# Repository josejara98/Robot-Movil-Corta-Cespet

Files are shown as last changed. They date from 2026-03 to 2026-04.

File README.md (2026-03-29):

# 🤖 Prototipo de Robot móvil Cortacésped

Este repositorio contiene el diseño de hardware y el firmware base para la unidad de control central de un robot móvil cortacésped teleoperado

El núcleo de este proyecto es una **PCB personalizada**  diseñada para gestionar potencia, navegación y sistema de seguridad utilizando el microcontrolador **ESP32-S3**.

## Especificaciones Técnicas de la PCB

Nuestra especialización se centra en la integración de sensores y la gestión de actuadores de potencia:

### Cerebro y Conectividad
* **MCU:** `ESP32-S3-WROOM-1`. Doble núcleo con soporte nativo para Wi-Fi y Bluetooth

### Sistema de Seguridad y Detección de Obstáculos
El robot implementa una estrategia de seguridad de dos niveles:
1.  **Nivel Preventivo (Ultrasonidos):** 3 sensores ultrasónicos estratégicamente posicionados para la detección de obstáculos a distancia
2.  **Nivel de Contacto (Bumpers):** 4 finales de carrera instalados en el chasis como "Bumpers". Funcionan como la última barrera física
* **Regulación:** `LDL1117S33R`. LDO de alta eficiencia para una alimentación estable de 3.3V.
* **Precisión de Batería:** `ADS1015LIDGSR`. ADC externo de 12 bits para un monitoreo crítico del voltaje

### Navegación y Movimiento
* **IMU:** `IIM-42652`. Sensor de 6 ejes de grado industrial para mantener el rumbo y detectar inclinaciones peligrosas.
* **Control de Tracción:** Pines de salida (Dupont) para conectar un **driver de motor DC externo** para el desplazamiento del robot.

### Sistema de Corte (Brushless)
La PCB cuenta con salidas específicas para controlar **3 ESC (Electronic Speed Controllers)** independientes:
* **2 Motores Brushless:** Dedicados al corte principal de césped.
* **1 Motor Brushless:** Dedicado a la función de bordeadora

### Interfaz de Usuario
* **Buzzer SMT:** `CMI-9705-0580-SMT-TR`. Notifica mediante códigos acústicos:
    * **Movimiento inminente:** Alerta antes de activar cuchillas o tracción.
    * **Batería Baja:** Alerta de retorno a base.

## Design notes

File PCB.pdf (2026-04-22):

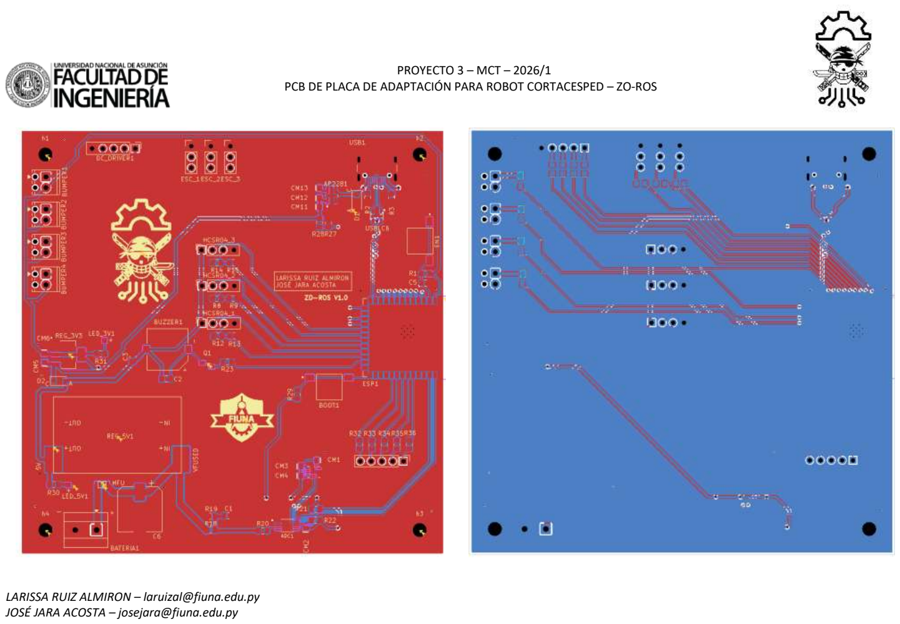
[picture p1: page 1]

PROYECTO 3 – MCT – 2026/1
PCB DE PLACA DE ADAPTACIÓN PARA ROBOT CORTACESPED – ZO-ROS

LARISSA RUIZ ALMIRON – laruizal@fiuna.edu.py JOSÉ JARA ACOSTA – josejara@fiuna.edu.py

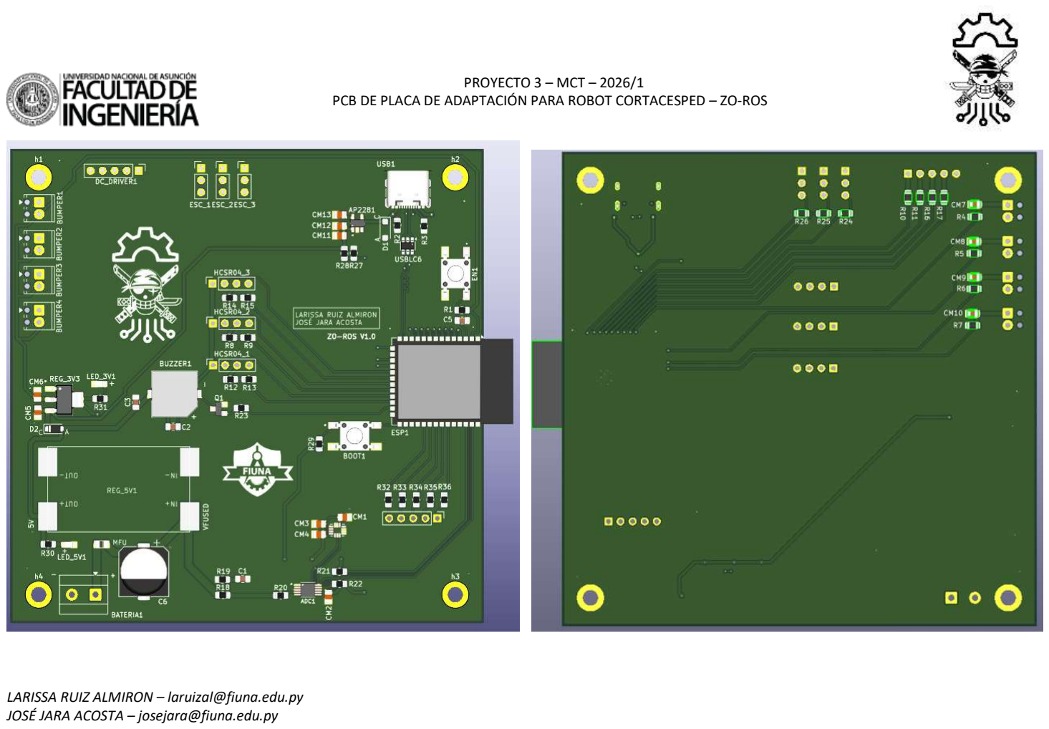
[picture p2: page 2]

PROYECTO 3 – MCT – 2026/1
PCB DE PLACA DE ADAPTACIÓN PARA ROBOT CORTACESPED – ZO-ROS

LARISSA RUIZ ALMIRON – laruizal@fiuna.edu.py JOSÉ JARA ACOSTA – josejara@fiuna.edu.py

PROYECTO 3 – MCT – 2026/1
PCB DE PLACA DE ADAPTACIÓN PARA ROBOT CORTACESPED – ZO-ROS

LARISSA RUIZ ALMIRON – laruizal@fiuna.edu.py JOSÉ JARA ACOSTA – josejara@fiuna.edu.py

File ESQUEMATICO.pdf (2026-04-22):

PROYECTO 3 – MCT – 2026/1
ESQUEMATICO DE PLACA DE ADAPTACIÓN PARA ROBOT CORTACESPED – ZO-ROS

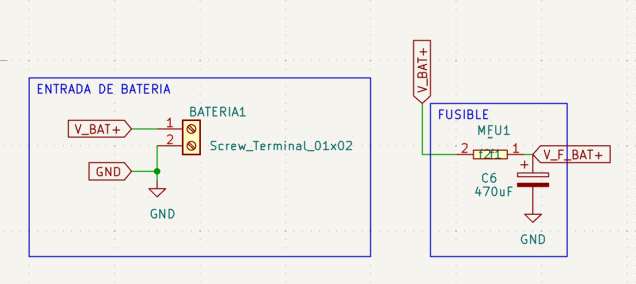
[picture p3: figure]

LARISSA RUIZ ALMIRON – laruizal@fiuna.edu.py JOSÉ JARA ACOSTA – josejara@fiuna.edu.py

En el diseño de la placa se planteó una arquitectura modular, separando claramente las funciones principales del sistema para facilitar

tanto el análisis como la implementación física

La alimentación del sistema comienza en la entrada de

batería, donde se utiliza una bornera para asegurar una

conexión firme. Inmediatamente después se incorpora un

fusible, con el objetivo de proteger la placa frente a

sobrecorrientes o posibles cortocircuitos. Además, se

añadió un capacitor electrolítico de 470 µF, cuya función es

estabilizar la tensión de entrada y absorber variaciones

bruscas provocadas principalmente por el funcionamiento

de los motores.

PROYECTO 3 – MCT – 2026/1
ESQUEMATICO DE PLACA DE ADAPTACIÓN PARA ROBOT CORTACESPED – ZO-ROS

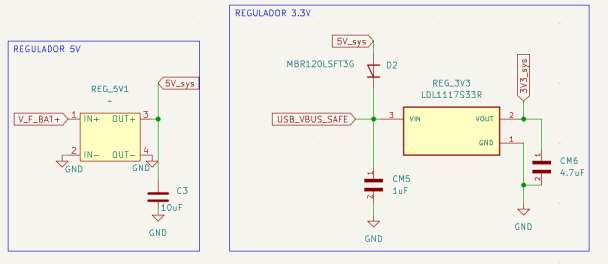
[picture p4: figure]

LARISSA RUIZ ALMIRON – laruizal@fiuna.edu.py JOSÉ JARA ACOSTA – josejara@fiuna.edu.py

A partir de la alimentación, se implementa un regulador tipo buck para obtener una línea de 5V. Esta elección se debe a que el sistema trabaja con una batería cuyo voltaje es superior, y un regulador lineal no sería eficiente debido a las pérdidas térmicas. El capacitor en la salida del regulador ayuda a mantener una tensión más estable frente a cambios de carga.

Posteriormente, se genera la línea de 3.3V mediante un regulador LDO, ya que este nivel es requerido por el ESP32 y varios sensores. Se incluyó un diodo Schottky en la entrada del regulador para evitar corrientes inversas, especialmente considerando que el sistema también puede alimentarse desde el puerto USB. Los capacitores asociados al regulador cumplen la función de desacople y estabilidad, tal como recomiendan los datasheets.

PROYECTO 3 – MCT – 2026/1
ESQUEMATICO DE PLACA DE ADAPTACIÓN PARA ROBOT CORTACESPED – ZO-ROS

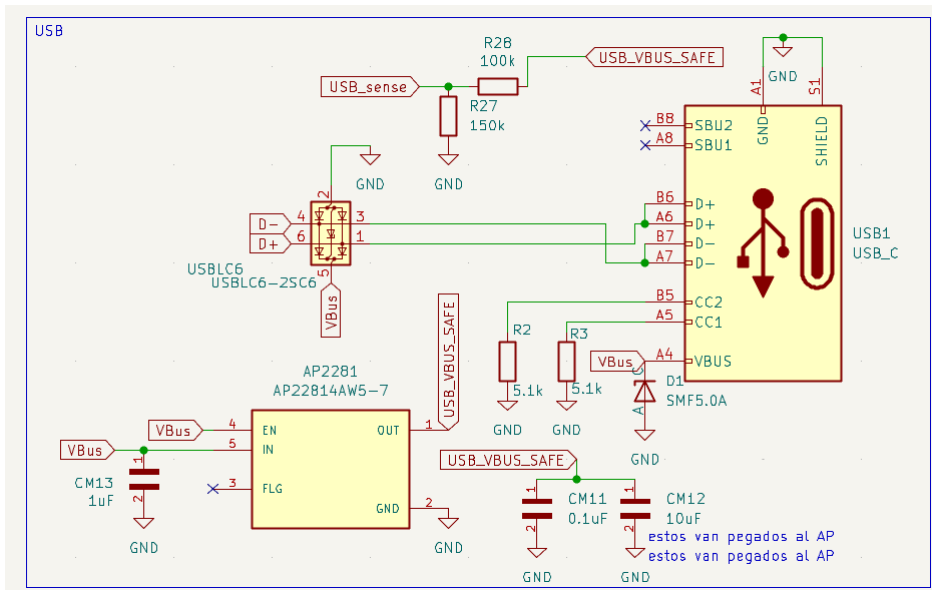
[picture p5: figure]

LARISSA RUIZ ALMIRON – laruizal@fiuna.edu.py JOSÉ JARA ACOSTA – josejara@fiuna.edu.py

El bloque USB fue diseñado no solo para

comunicación, | sino | también | considerando

aspectos de protección. Se incorporó un arreglo de

protección ESD en las líneas de datos y un diodo

TVS en la línea de VBUS para proteger frente a

descargas. Además, se utilizaron resistencias en

las líneas CC para cumplir con la especificación de

USB-C. También se implementa un circuito de

control de alimentación mediante un switch

dedicado, lo que permite gestionar de forma segura

la energía proveniente del USB.

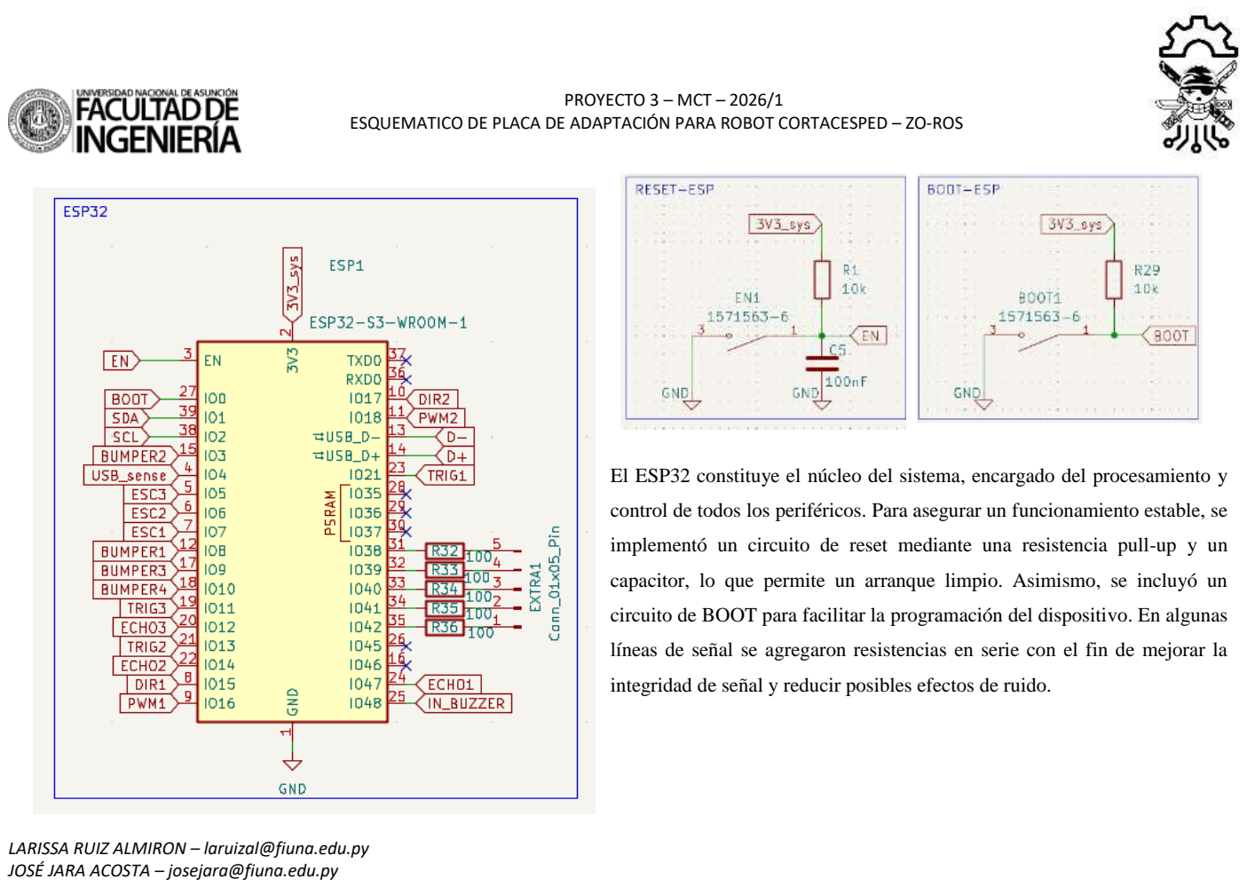
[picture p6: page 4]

PROYECTO 3 – MCT – 2026/1
ESQUEMATICO DE PLACA DE ADAPTACIÓN PARA ROBOT CORTACESPED – ZO-ROS

LARISSA RUIZ ALMIRON – laruizal@fiuna.edu.py JOSÉ JARA ACOSTA – josejara@fiuna.edu.py

El ESP32 constituye el núcleo del sistema, encargado del procesamiento y

control de todos los periféricos. Para asegurar un funcionamiento estable, se

implementó un circuito de reset mediante una resistencia pull-up y un

capacitor, lo que permite un arranque limpio. Asimismo, se incluyó un

circuito de BOOT para facilitar la programación del dispositivo. En algunas

líneas de señal se agregaron resistencias en serie con el fin de mejorar la

integridad de señal y reducir posibles efectos de ruido.

PROYECTO 3 – MCT – 2026/1
ESQUEMATICO DE PLACA DE ADAPTACIÓN PARA ROBOT CORTACESPED – ZO-ROS

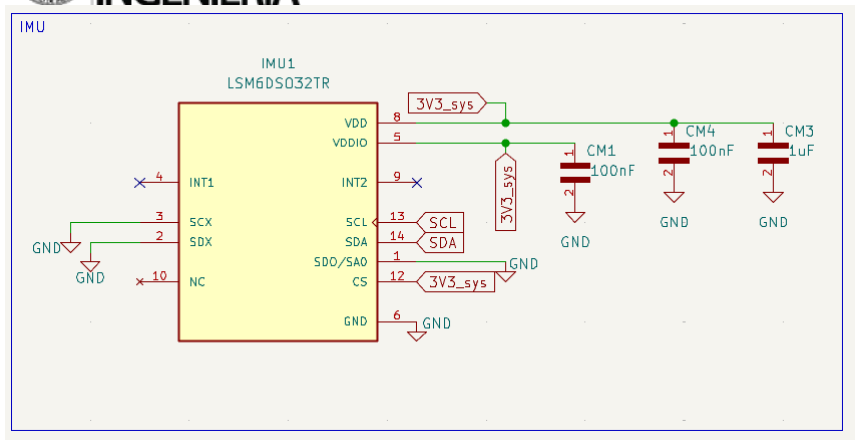
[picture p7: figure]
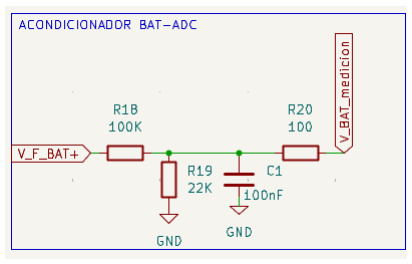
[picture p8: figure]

LARISSA RUIZ ALMIRON – laruizal@fiuna.edu.py JOSÉ JARA ACOSTA – josejara@fiuna.edu.py

En cuanto a los sensores, se incorporó una IMU conectada

mediante I2C, la cual cuenta con capacitores de desacople

ubicados próximos a sus pines de alimentación, siguiendo las

recomendaciones del fabricante. Para la medición de la batería, se

utilizó un ADC externo, ya que el ADC interno del ESP32 no

ofrece la precisión requerida. Este ADC también se comunica

mediante I2C y cuenta con resistencias pull-up adecuadas.

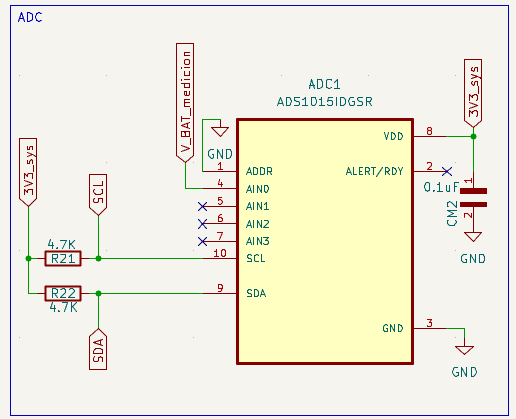
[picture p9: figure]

La medición del voltaje de batería se realiza a través

de un divisor resistivo, el cual reduce la tensión a

un nivel seguro para el ADC. Adicionalmente, se

incorporó un filtro RC para disminuir el ruido

presente en la señal, mejorando así la calidad de la

medición.

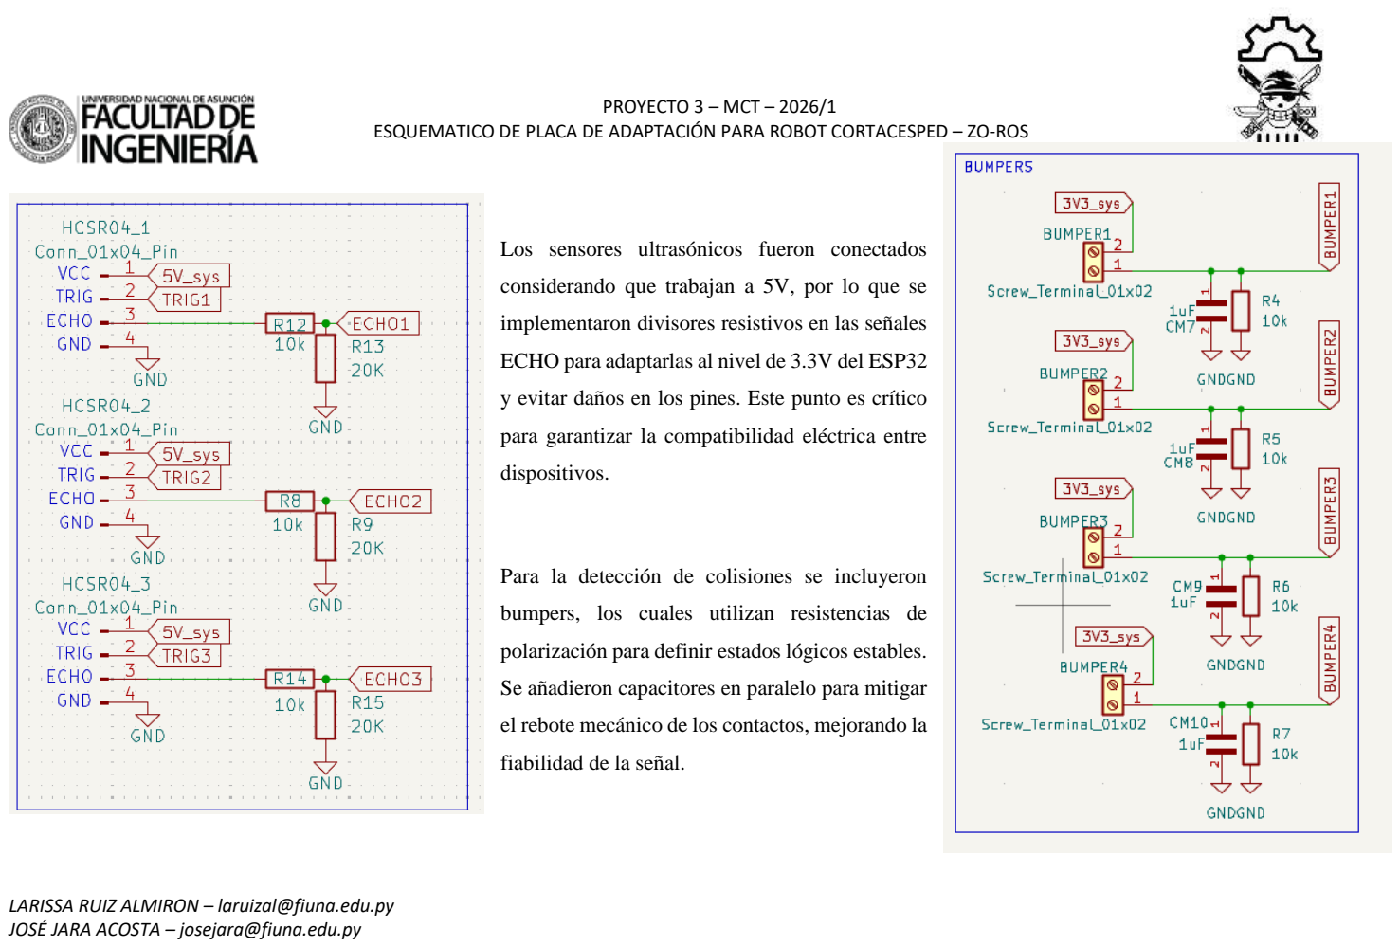
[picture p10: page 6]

PROYECTO 3 – MCT – 2026/1
ESQUEMATICO DE PLACA DE ADAPTACIÓN PARA ROBOT CORTACESPED – ZO-ROS

LARISSA RUIZ ALMIRON – laruizal@fiuna.edu.py JOSÉ JARA ACOSTA – josejara@fiuna.edu.py

Los sensores ultrasónicos fueron conectados

considerando que trabajan a 5V, por lo que se

implementaron divisores resistivos en las señales

ECHO para adaptarlas al nivel de 3.3V del ESP32

y evitar daños en los pines. Este punto es crítico

para garantizar la compatibilidad eléctrica entre

dispositivos.

Para la detección de colisiones se incluyeron

bumpers, los cuales utilizan resistencias de

polarización para definir estados lógicos estables.

Se añadieron capacitores en paralelo para mitigar

el rebote mecánico de los contactos, mejorando la

fiabilidad de la señal.

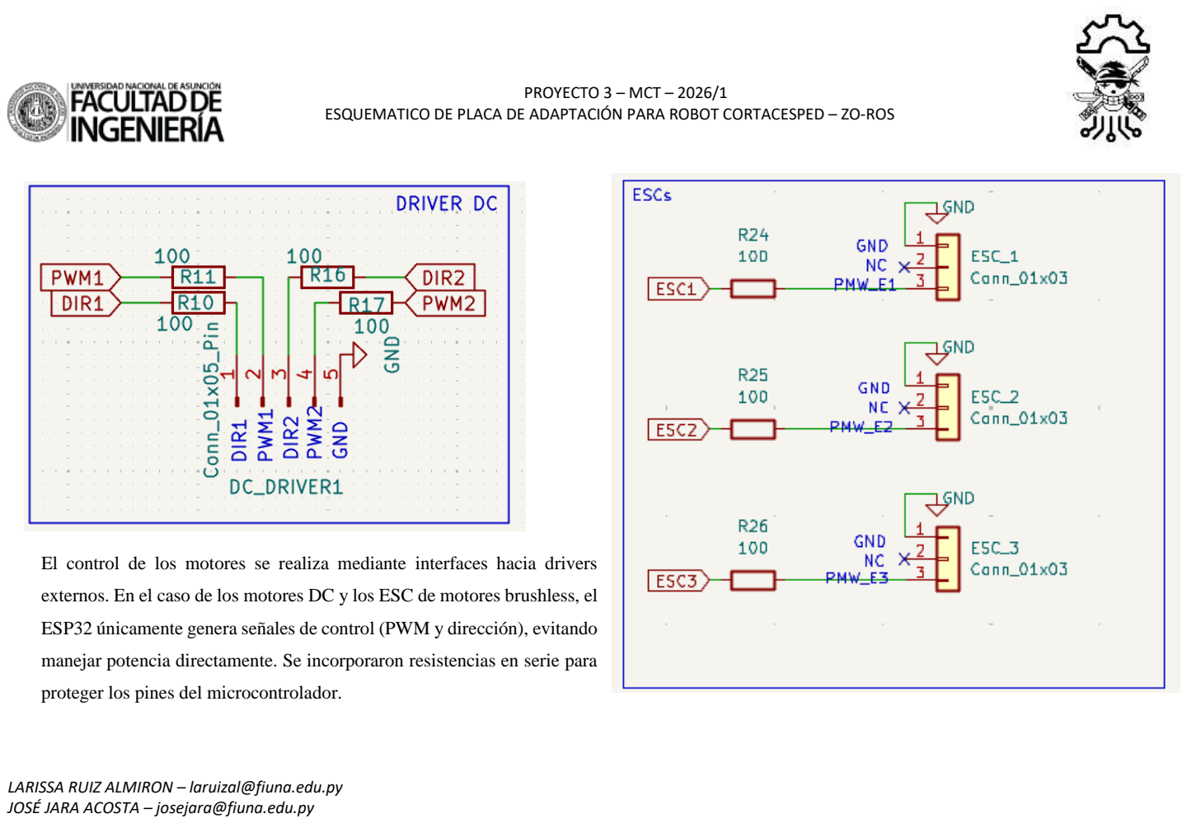
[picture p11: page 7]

PROYECTO 3 – MCT – 2026/1
ESQUEMATICO DE PLACA DE ADAPTACIÓN PARA ROBOT CORTACESPED – ZO-ROS

LARISSA RUIZ ALMIRON – laruizal@fiuna.edu.py JOSÉ JARA ACOSTA – josejara@fiuna.edu.py

El control de los motores se realiza mediante interfaces hacia drivers

externos. En el caso de los motores DC y los ESC de motores brushless, el

ESP32 únicamente genera señales de control (PWM y dirección), evitando

manejar potencia directamente. Se incorporaron resistencias en serie para

proteger los pines del microcontrolador.

PROYECTO 3 – MCT – 2026/1
ESQUEMATICO DE PLACA DE ADAPTACIÓN PARA ROBOT CORTACESPED – ZO-ROS

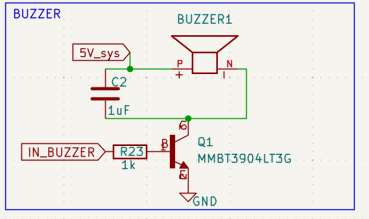
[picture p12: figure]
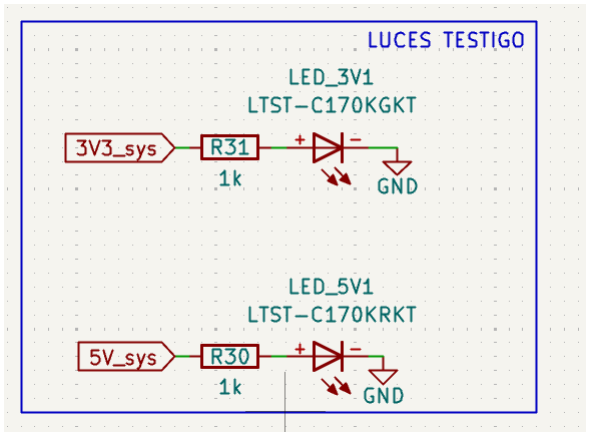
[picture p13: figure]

LARISSA RUIZ ALMIRON – laruizal@fiuna.edu.py JOSÉ JARA ACOSTA – josejara@fiuna.edu.py

El buzzer se controla mediante un transistor en configuración de conmutación, ya que el

ESP32 no puede suministrar la corriente necesaria de forma directa. La resistencia en la

base asegura el correcto funcionamiento del transistor.

Finalmente, se añadieron LEDs indicadores para las líneas de 3.3V y 5V,

lo que permite verificar visualmente el estado de la alimentación del

sistema.

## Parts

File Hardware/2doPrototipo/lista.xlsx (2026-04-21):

Reference | Qty | Value | DNP | Exclude from BOM | Exclude from Board | Footprint | Datasheet
R1,R4,R5,R6,R7,R8,R12,R14,R29 | 9 | 10k |  |  |  | Resistor_SMD:R_0805_2012Metric_Pad1.20x1.40mm_HandSolder | ~
R2,R3 | 2 | 5.1k |  |  |  | Resistor_SMD:R_0805_2012Metric_Pad1.20x1.40mm_HandSolder | ~
R9,R13,R15 | 3 | 20K |  |  |  | Resistor_SMD:R_0805_2012Metric_Pad1.20x1.40mm_HandSolder | ~
R10,R11,R16,R17,R20,R24,R25,R26,R32,R33,R34,R35,R36 | 13 | 100 |  |  |  | Resistor_SMD:R_0805_2012Metric_Pad1.20x1.40mm_HandSolder | ~
R18 | 1 | 100K |  |  |  | Resistor_SMD:R_0805_2012Metric_Pad1.20x1.40mm_HandSolder | ~
R19 | 1 | 22K |  |  |  | Resistor_SMD:R_0805_2012Metric_Pad1.20x1.40mm_HandSolder | ~
R21,R22 | 2 | 4.7K |  |  |  | Resistor_SMD:R_0805_2012Metric_Pad1.20x1.40mm_HandSolder | ~
R23,R30,R31 | 3 | 1k |  |  |  | Resistor_SMD:R_0805_2012Metric_Pad1.20x1.40mm_HandSolder | ~
R27 | 1 | 150k |  |  |  | Resistor_SMD:R_0805_2012Metric_Pad1.20x1.40mm_HandSolder | ~
R28 | 1 | 100k |  |  |  | Resistor_SMD:R_0805_2012Metric_Pad1.20x1.40mm_HandSolder | ~
REG_3V3 | 1 | LDL1117S33R |  |  |  | LDL1117S33R:SOT230P700X180-4N
REG_5V1 | 1 | ~ |  |  |  | Mini590.pretty:MINI590
USB1 | 1 | USB_C |  |  |  | Connector_USB:USB_C_Receptacle_GCT_USB4105-xx-A_16P_TopMnt_Horizontal | https://www.usb.org/sites/default/files/documents/usb_type-c.zip
USBLC6 | 1 | USBLC6-2SC6 |  |  |  | Package_TO_SOT_SMD:SOT-23-6 | https://www.st.com/resource/en/datasheet/usblc6-2.pdf

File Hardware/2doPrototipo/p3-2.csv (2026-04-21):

Reference | Qty | Value | DNP | Exclude from BOM | Exclude from Board | Footprint | Datasheet
ADC1 | 1 | ADS1015IDGSR |  |  |  | ADS1015IDGSR:SOP50P490X110-10N
AP2281 | 1 | AP22814AW5-7 |  |  |  | AP22814AW5-7:SOT95P285X140-5N
BATERIA1 | 1 | Screw_Terminal_01x02 |  |  |  | TerminalBlock_MetzConnect:TerminalBlock_MetzConnect_Type055_RT01502HDWU_1x02_P5.00mm_Horizontal | ~
BOOT1,EN1 | 2 | 1571563-6 |  |  |  | 1571563-6:SW_1571563-6
BUMPER1,BUMPER2,BUMPER3,BUMPER4 | 4 | Screw_Terminal_01x02 |  |  |  | TerminalBlock_Phoenix:TerminalBlock_Phoenix_MPT-0,5-2-2.54_1x02_P2.54mm_Horizontal | ~
BUZZER1 | 1 | CMI-9705-0580-SMT-TR |  |  |  | CMI-9705-0580-SMT-TR:CUI_CMI-9705-0580-SMT-TR
C1,C5 | 2 | 100nF |  |  |  | Capacitor_SMD:C_0805_2012Metric_Pad1.18x1.45mm_HandSolder | ~
C2 | 1 | 1uF |  |  |  | Capacitor_SMD:C_0805_2012Metric_Pad1.18x1.45mm_HandSolder | ~
C3 | 1 | 10uF |  |  |  | Capacitor_SMD:C_0805_2012Metric_Pad1.18x1.45mm_HandSolder | ~
C6 | 1 | 470uF |  |  |  | Capacitor_SMD:CP_Elec_10x10 | ~
CM1,CM4 | 2 | 100nF |  |  |  | 08056D104KAT2A:CAPC2012X140N
CM2,CM11 | 2 | 0.1uF |  |  |  | 08056D104KAT2A:CAPC2012X140N
CM3,CM5,CM7,CM8,CM9,CM10,CM13 | 7 | 1uF |  |  |  | 08056D104KAT2A:CAPC2012X140N
CM6 | 1 | 4.7uF |  |  |  | 08056D104KAT2A:CAPC2012X140N
CM12 | 1 | 10uF |  |  |  | 08056D104KAT2A:CAPC2012X140N
D1 | 1 | SMF5.0A |  |  |  | SMF5.0A:P37_SOD-123FL | https://diotec.com/de/produktliste/Z.html
D2 | 1 | MBR120LSFT3G |  |  |  | SMF5.0A:P37_SOD-123FL | https://diotec.com/de/produktliste/Z.html
DC_DRIVER1,EXTRA1 | 2 | Conn_01x05_Pin |  |  |  | Connector_PinHeader_2.54mm:PinHeader_1x05_P2.54mm_Vertical | ~
ESC_1,ESC_2,ESC_3 | 3 | Conn_01x03 |  |  |  | Connector_PinHeader_2.54mm:PinHeader_1x03_P2.54mm_Vertical | ~
ESP1 | 1 | ESP32-S3-WROOM-1 |  |  |  | RF_Module:ESP32-S3-WROOM-1 | https://www.espressif.com/sites/default/files/documentation/esp32-s3-wroom-1_wroom-1u_datasheet_en.pdf
HCSR04_1,HCSR04_2,HCSR04_3 | 3 | Conn_01x04_Pin |  |  |  | Connector_PinSocket_2.54mm:PinSocket_1x04_P2.54mm_Vertical | ~
IMU1 | 1 | LSM6DSO32TR |  |  |  | LSM6DSO32TR:XDCR_LSM6DSO32TR
LED_3V1 | 1 | LTST-C170KGKT |  |  |  | LTST-C170KGKT:DIOC200X125X110
LED_5V1 | 1 | LTST-C170KRKT |  |  |  | LTST-C170KRKT:DIOC200X125X110
MFU1 | 1 | ~ |  |  |  | MFU0805FF01000PW00.pretty:MFU0805FF01000PW00
Q1 | 1 | MMBT3904LT3G |  |  |  | MMBT3904LT3G:SOT23
R1,R4,R5,R6,R7,R8,R12,R14,R29 | 9 | 10k |  |  |  | Resistor_SMD:R_0805_2012Metric_Pad1.20x1.40mm_HandSolder | ~
R2,R3 | 2 | 5.1k |  |  |  | Resistor_SMD:R_0805_2012Metric_Pad1.20x1.40mm_HandSolder | ~
R9,R13,R15 | 3 | 20K |  |  |  | Resistor_SMD:R_0805_2012Metric_Pad1.20x1.40mm_HandSolder | ~
R10,R11,R16,R17,R20,R24,R25,R26,R32,R33,R34,R35,R36 | 13 | 100 |  |  |  | Resistor_SMD:R_0805_2012Metric_Pad1.20x1.40mm_HandSolder | ~
R18 | 1 | 100K |  |  |  | Resistor_SMD:R_0805_2012Metric_Pad1.20x1.40mm_HandSolder | ~
R19 | 1 | 22K |  |  |  | Resistor_SMD:R_0805_2012Metric_Pad1.20x1.40mm_HandSolder | ~
R21,R22 | 2 | 4.7K |  |  |  | Resistor_SMD:R_0805_2012Metric_Pad1.20x1.40mm_HandSolder | ~
R23,R30,R31 | 3 | 1k |  |  |  | Resistor_SMD:R_0805_2012Metric_Pad1.20x1.40mm_HandSolder | ~
R27 | 1 | 150k |  |  |  | Resistor_SMD:R_0805_2012Metric_Pad1.20x1.40mm_HandSolder | ~
R28 | 1 | 100k |  |  |  | Resistor_SMD:R_0805_2012Metric_Pad1.20x1.40mm_HandSolder | ~
REG_3V3 | 1 | LDL1117S33R |  |  |  | LDL1117S33R:SOT230P700X180-4N
REG_5V1 | 1 | ~ |  |  |  | Mini590.pretty:MINI590
USB1 | 1 | USB_C |  |  |  | Connector_USB:USB_C_Receptacle_GCT_USB4105-xx-A_16P_TopMnt_Horizontal | https://www.usb.org/sites/default/files/documents/usb_type-c.zip
USBLC6 | 1 | USBLC6-2SC6 |  |  |  | Package_TO_SOT_SMD:SOT-23-6 | https://www.st.com/resource/en/datasheet/usblc6-2.pdf

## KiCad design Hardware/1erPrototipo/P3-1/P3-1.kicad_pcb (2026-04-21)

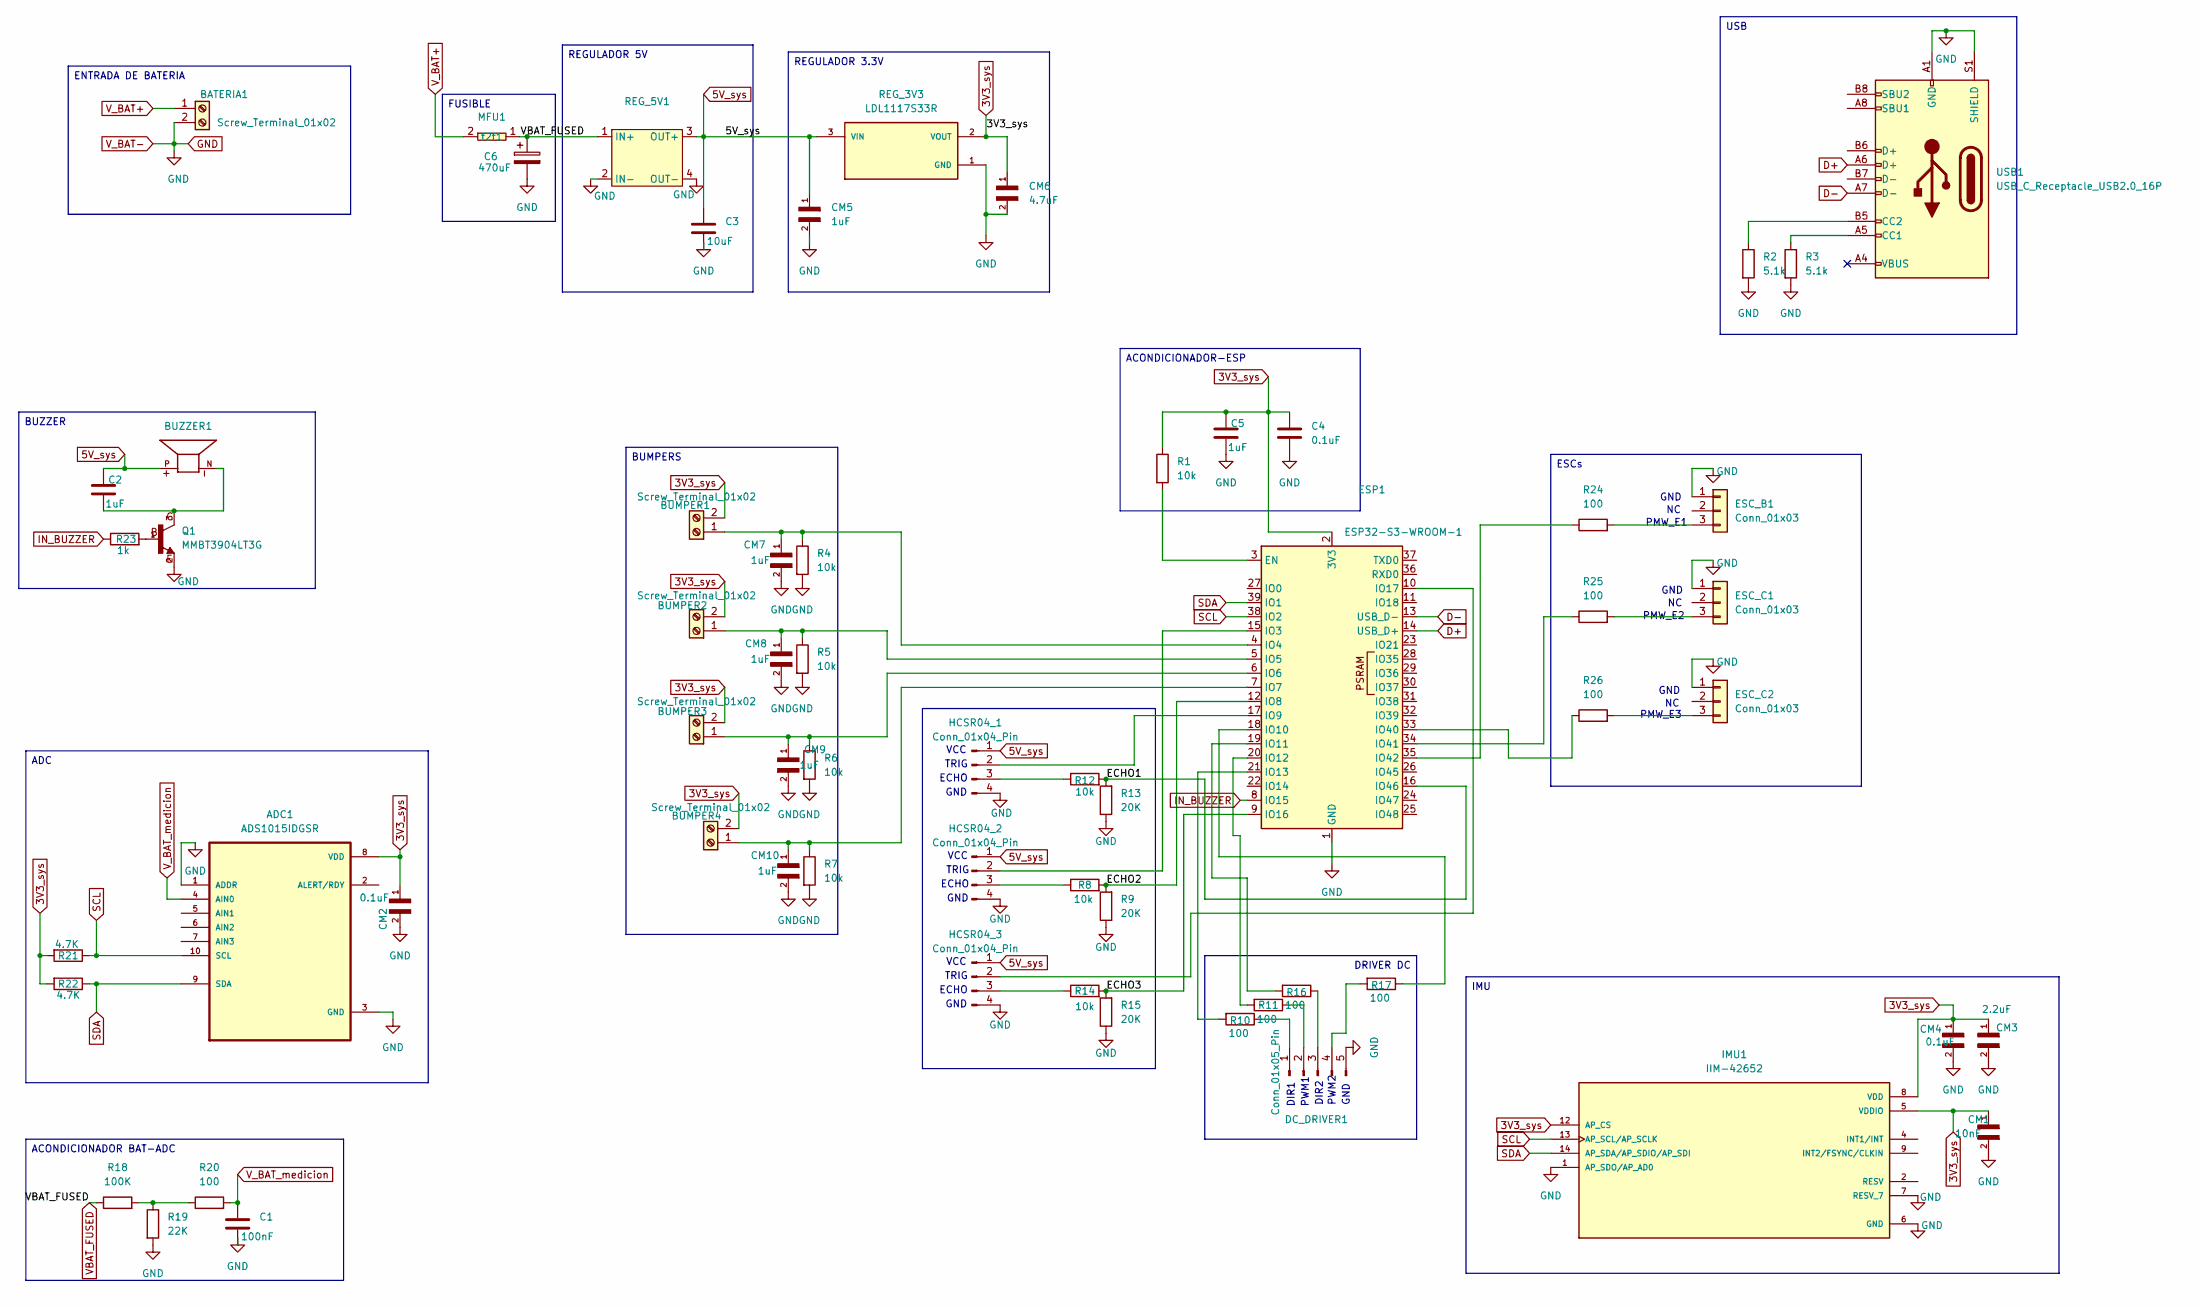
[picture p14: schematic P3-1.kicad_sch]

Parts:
ADC1: ADS1015IDGSR; SOP50P490X110-10N
BATERIA1: Screw_Terminal_01x02; TerminalBlock_MetzConnect_Type055_RT01502HDWU_1x02_P5.00mm_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
BUMPER1, BUMPER2, BUMPER3, BUMPER4: Screw_Terminal_01x02; TerminalBlock_Phoenix_MPT-0,5-2-2.54_1x02_P2.54mm_Horizontal
BUZZER1: CMI-9705-0580-SMT-TR; CUI_CMI-9705-0580-SMT-TR; PARTREV 1.0
C1: 100nF; C_0805_2012Metric_Pad1.18x1.45mm_HandSolder
C2, C5: 1uF; C_0805_2012Metric_Pad1.18x1.45mm_HandSolder
C3: 10uF; C_0805_2012Metric_Pad1.18x1.45mm_HandSolder
C4: 0.1uF; C_0805_2012Metric_Pad1.18x1.45mm_HandSolder
C6: 470uF; CP_Elec_10x10
CM1: 10nF; CAPC2012X140N; DigiKey_Part_Number 478-08056D104KAT2ACT-ND
CM2, CM4: 0.1uF; CAPC2012X140N; DigiKey_Part_Number 478-08056D104KAT2ACT-ND
CM3: 2.2uF; CAPC2012X140N; DigiKey_Part_Number 478-08056D104KAT2ACT-ND
CM5, CM7, CM8, CM9, CM10: 1uF; CAPC2012X140N; DigiKey_Part_Number 478-08056D104KAT2ACT-ND
CM6: 4.7uF; CAPC2012X140N; DigiKey_Part_Number 478-08056D104KAT2ACT-ND
DC_DRIVER1: Conn_01x05_Pin; PinHeader_1x05_P2.54mm_Vertical
ESC_B1: Conn_01x03; PinHeader_1x03_P2.54mm_Vertical
ESC_C1, ESC_C2: Conn_01x03; PinHeader_1x03_P2.54mm_Vertical
ESP1: ESP32-S3-WROOM-1
HCSR04_1, HCSR04_2, HCSR04_3: Conn_01x04_Pin; PinSocket_1x04_P2.54mm_Vertical
IMU1: IIM-42652; PQFN50P250X300X97-14N; PARTREV 1.0
MFU1: MFU0603FF01000PW00
Q1: MMBT3904LT3G; SOT23; DigiKey_Part_Number MMBT3904LT3GOSCT-ND
R1, R4, R5, R6, R7, R8, R12, R14: 10k; R_0805_2012Metric_Pad1.20x1.40mm_HandSolder
R2, R3: 5.1k; R_0805_2012Metric_Pad1.20x1.40mm_HandSolder
R9, R13, R15: 20K; R_0805_2012Metric_Pad1.20x1.40mm_HandSolder
R10, R11, R16, R17, R20, R24, R25, R26: 100; R_0805_2012Metric_Pad1.20x1.40mm_HandSolder
R18: 100K; R_0805_2012Metric_Pad1.20x1.40mm_HandSolder
R19: 22K; R_0805_2012Metric_Pad1.20x1.40mm_HandSolder
R21, R22: 4.7K; R_0805_2012Metric_Pad1.20x1.40mm_HandSolder
R23: 1k; R_0805_2012Metric_Pad1.20x1.40mm_HandSolder
REG_3V3: LDL1117S33R; SOT230P700X180-4N; PARTREV 7
REG_5V1: MINI590
USB1: USB_C_Receptacle_USB2.0_16P; USB_C_Receptacle_GCT_USB4105-xx-A_16P_TopMnt_Horizontal

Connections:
3V3_sys: ADC1.8 (VDD), BUMPER1.2, BUMPER2.2, BUMPER3.2, BUMPER4.2, C4.1, C5.1, CM1.1, CM2.1, CM3.1, CM4.1, CM6.1, ESP1.2 (3V3), IMU1.5 (VDDIO), IMU1.8 (VDD), IMU1.12 (AP_CS), R1.1, R21.2, R22.2, REG_3V3.2 (VOUT), REG_3V3.4 (VOUT)
5V_sys: BUZZER1.P, C2.1, C3.1, CM5.1, HCSR04_1.1, HCSR04_2.1, HCSR04_3.1, REG_3V3.3 (VIN), REG_5V1.3 (OUT+)
/ECHO1: ESP1.16 (IO46), R12.2, R13.2
/ECHO2: ESP1.12 (IO8), R8.2, R9.2
/ECHO3: ESP1.9 (IO16), R14.2, R15.2
D+: ESP1.14 (USB_D+), USB1.A6 (D+)
D-: ESP1.13 (USB_D-), USB1.A7 (D-)
GND: ADC1.1 (ADDR), ADC1.3 (GND), BATERIA1.2, C1.2, C3.2, C4.2, C5.2, C6.2, CM1.2, CM2.2, CM3.2, CM4.2, CM5.2, CM6.2, CM7.2, CM8.2, CM9.2, CM10.2, DC_DRIVER1.5, ESC_B1.1, ESC_C1.1, ESC_C2.1, ESP1.1 (GND), ESP1.40 (GND), ESP1.41 (GND), HCSR04_1.4, HCSR04_2.4, HCSR04_3.4, IMU1.1 (AP_SDO/AP_AD0), IMU1.6 (GND), IMU1.7 (RESV_7), Q1.2, R2.2, R3.2, R4.2, R5.2, R6.2, R7.2, R9.1, R13.1, R15.1, R19.2, REG_3V3.1 (GND), REG_5V1.2 (IN-), REG_5V1.4 (OUT-), USB1.A1 (GND), USB1.A12 (GND), USB1.B1 (GND), USB1.B12 (GND), USB1.S1 (SHIELD)
IN_BUZZER: ESP1.8 (IO15), R23.1
unnamed: BUMPER1.1, CM7.1, ESP1.4 (IO4), R4.1
unnamed: BUMPER2.1, CM8.1, ESP1.5 (IO5), R5.1
unnamed: BUMPER3.1, CM9.1, ESP1.6 (IO6), R6.1
unnamed: BUMPER4.1, CM10.1, ESP1.7 (IO7), R7.1
unnamed: BUZZER1.N, C2.2, Q1.3
unnamed: DC_DRIVER1.1, R10.1
unnamed: DC_DRIVER1.2, R11.1
unnamed: DC_DRIVER1.3, R16.1
unnamed: DC_DRIVER1.4, R17.2
unnamed: ESC_B1.3, R24.2
unnamed: ESC_C1.3, R25.2
unnamed: ESC_C2.3, R26.2
unnamed: ESP1.3 (EN), R1.2
unnamed: ESP1.15 (IO3), HCSR04_2.2
unnamed: ESP1.17 (IO9), HCSR04_1.2
unnamed: ESP1.18 (IO10), R17.1
unnamed: ESP1.19 (IO11), R16.2
unnamed: ESP1.20 (IO12), R11.2
unnamed: ESP1.21 (IO13), R10.2
unnamed: ESP1.10 (IO17), HCSR04_3.2
unnamed: ESP1.33 (IO40), R26.1
unnamed: ESP1.34 (IO41), R25.1
unnamed: ESP1.35 (IO42), R24.1
unnamed: HCSR04_1.3, R12.1
unnamed: HCSR04_2.3, R8.1
unnamed: HCSR04_3.3, R14.1
unnamed: IMU1.2 (RESV), IMU1.3 (RESV), IMU1.10 (RESV), IMU1.11 (RESV)
unnamed: Q1.1, R23.2
unnamed: R18.2, R19.1, R20.1
unnamed: R3.1, USB1.A5 (CC1)
unnamed: R2.1, USB1.B5 (CC2)
SCL: ADC1.10 (SCL), ESP1.38 (IO2), IMU1.13 (AP_SCL/AP_SCLK), R21.1
SDA: ADC1.9 (SDA), ESP1.39 (IO1), IMU1.14 (AP_SDA/AP_SDIO/AP_SDI), R22.1
VBAT_FUSED: C6.1, MFU1.1 (f1), R18.1, REG_5V1.1 (IN+)
V_BAT+: BATERIA1.1, MFU1.2 (f2)
V_BAT_medicion: ADC1.4 (AIN0), C1.1, R20.2

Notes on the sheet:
TRIG
PWM2
GND
VCC
GND
ECHO
PMW_E2
PMW_E3
DIR2
DIR1
PWM1
PMW_E1
ADC
REGULADOR 3.3V
ENTRADA DE BATERIA
DRIVER DC
ACONDICIONADOR-ESP
BUMPERS
BUZZER
REGULADOR 5V
ESCs
ACONDICIONADOR BAT-ADC
USB
IMU
FUSIBLE

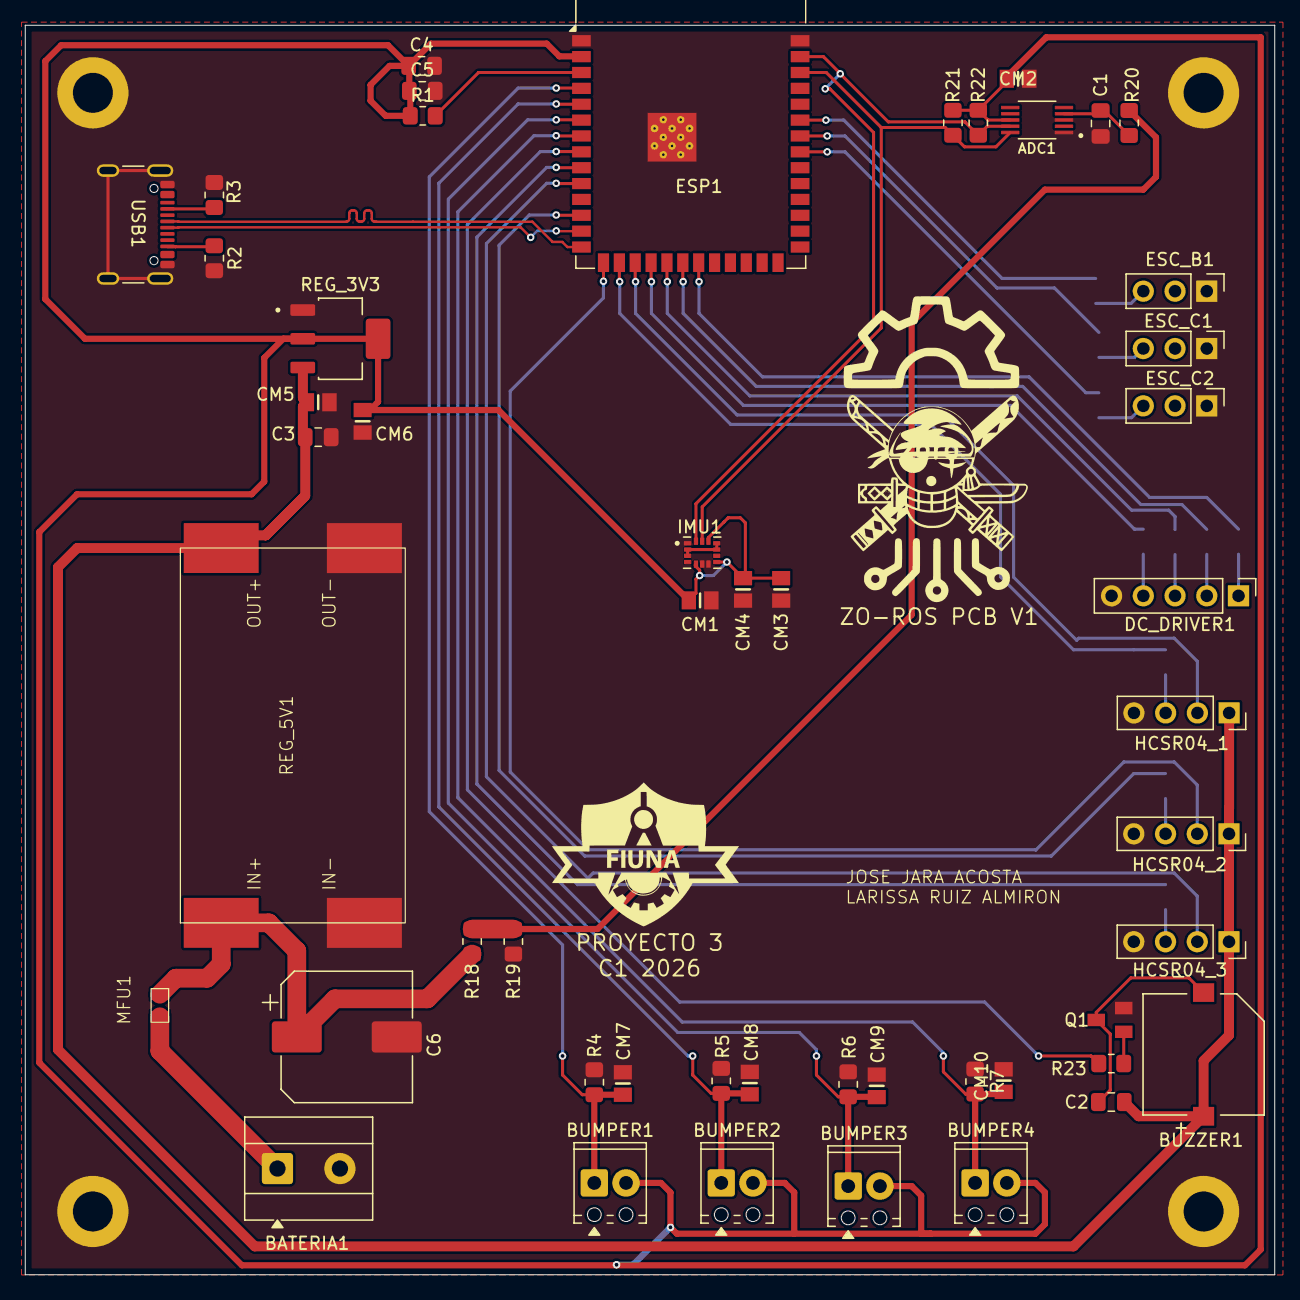
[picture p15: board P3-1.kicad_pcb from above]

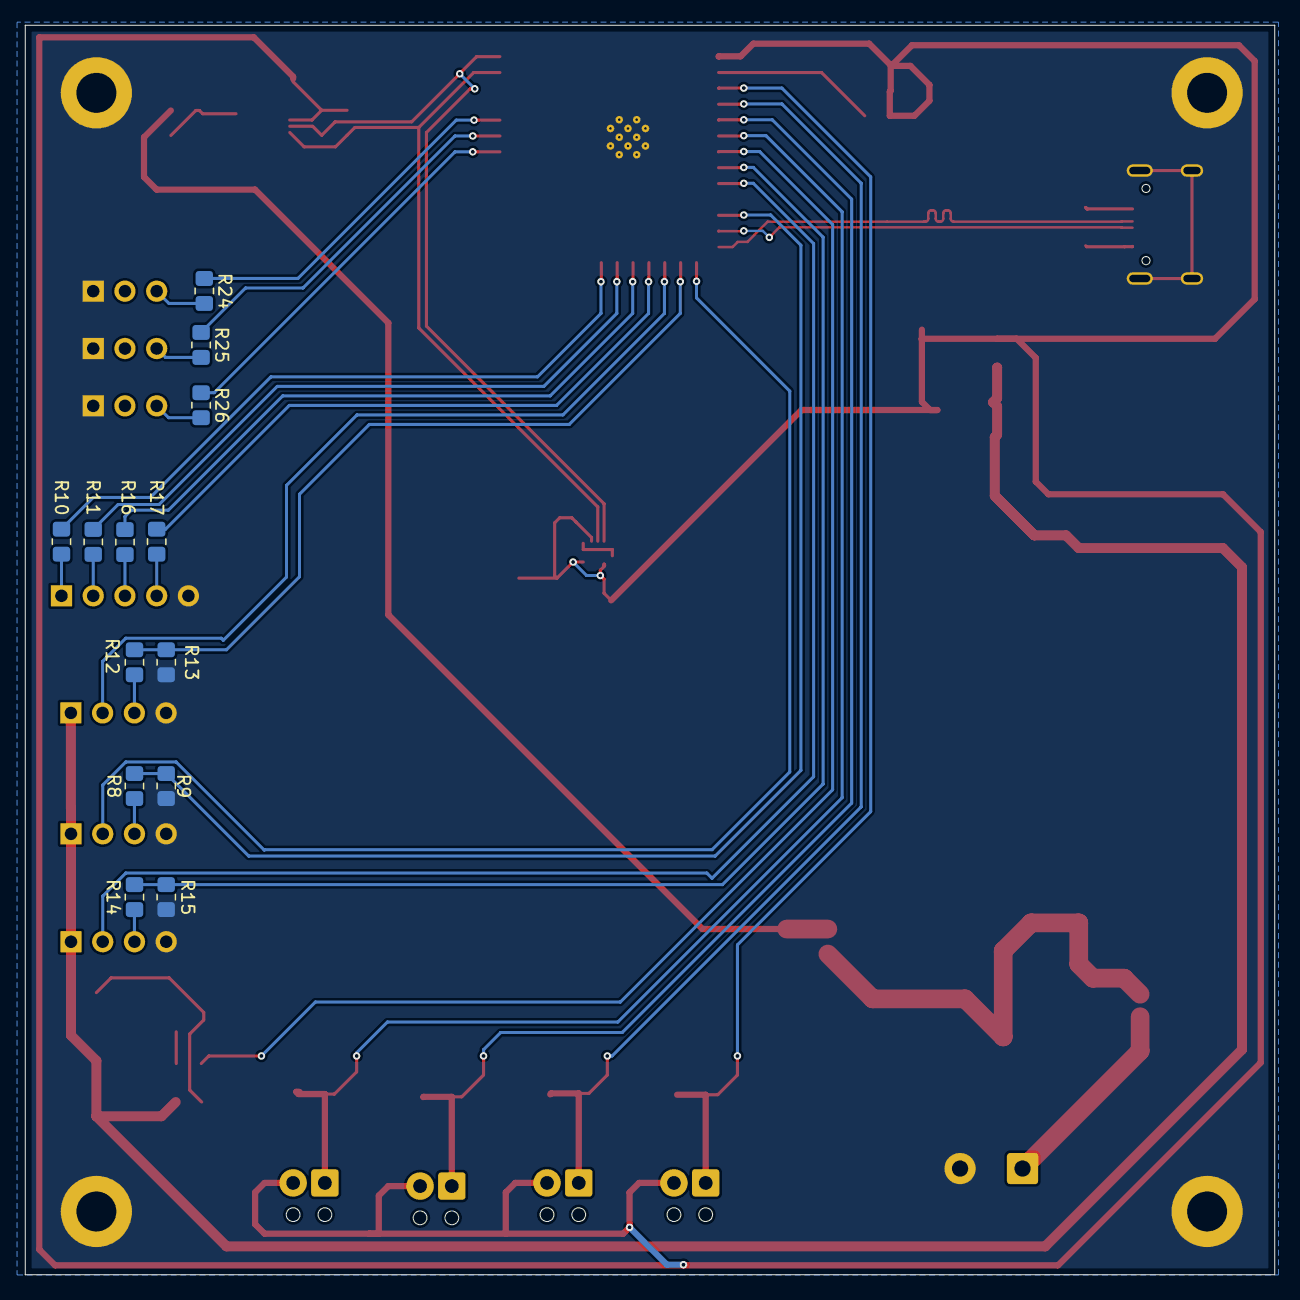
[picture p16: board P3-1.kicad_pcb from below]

Board: 2 copper layers, 100.0 x 100.0 mm, 64 parts (13 on the bottom side), 45 nets.

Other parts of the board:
zoro: LOGO; zoro

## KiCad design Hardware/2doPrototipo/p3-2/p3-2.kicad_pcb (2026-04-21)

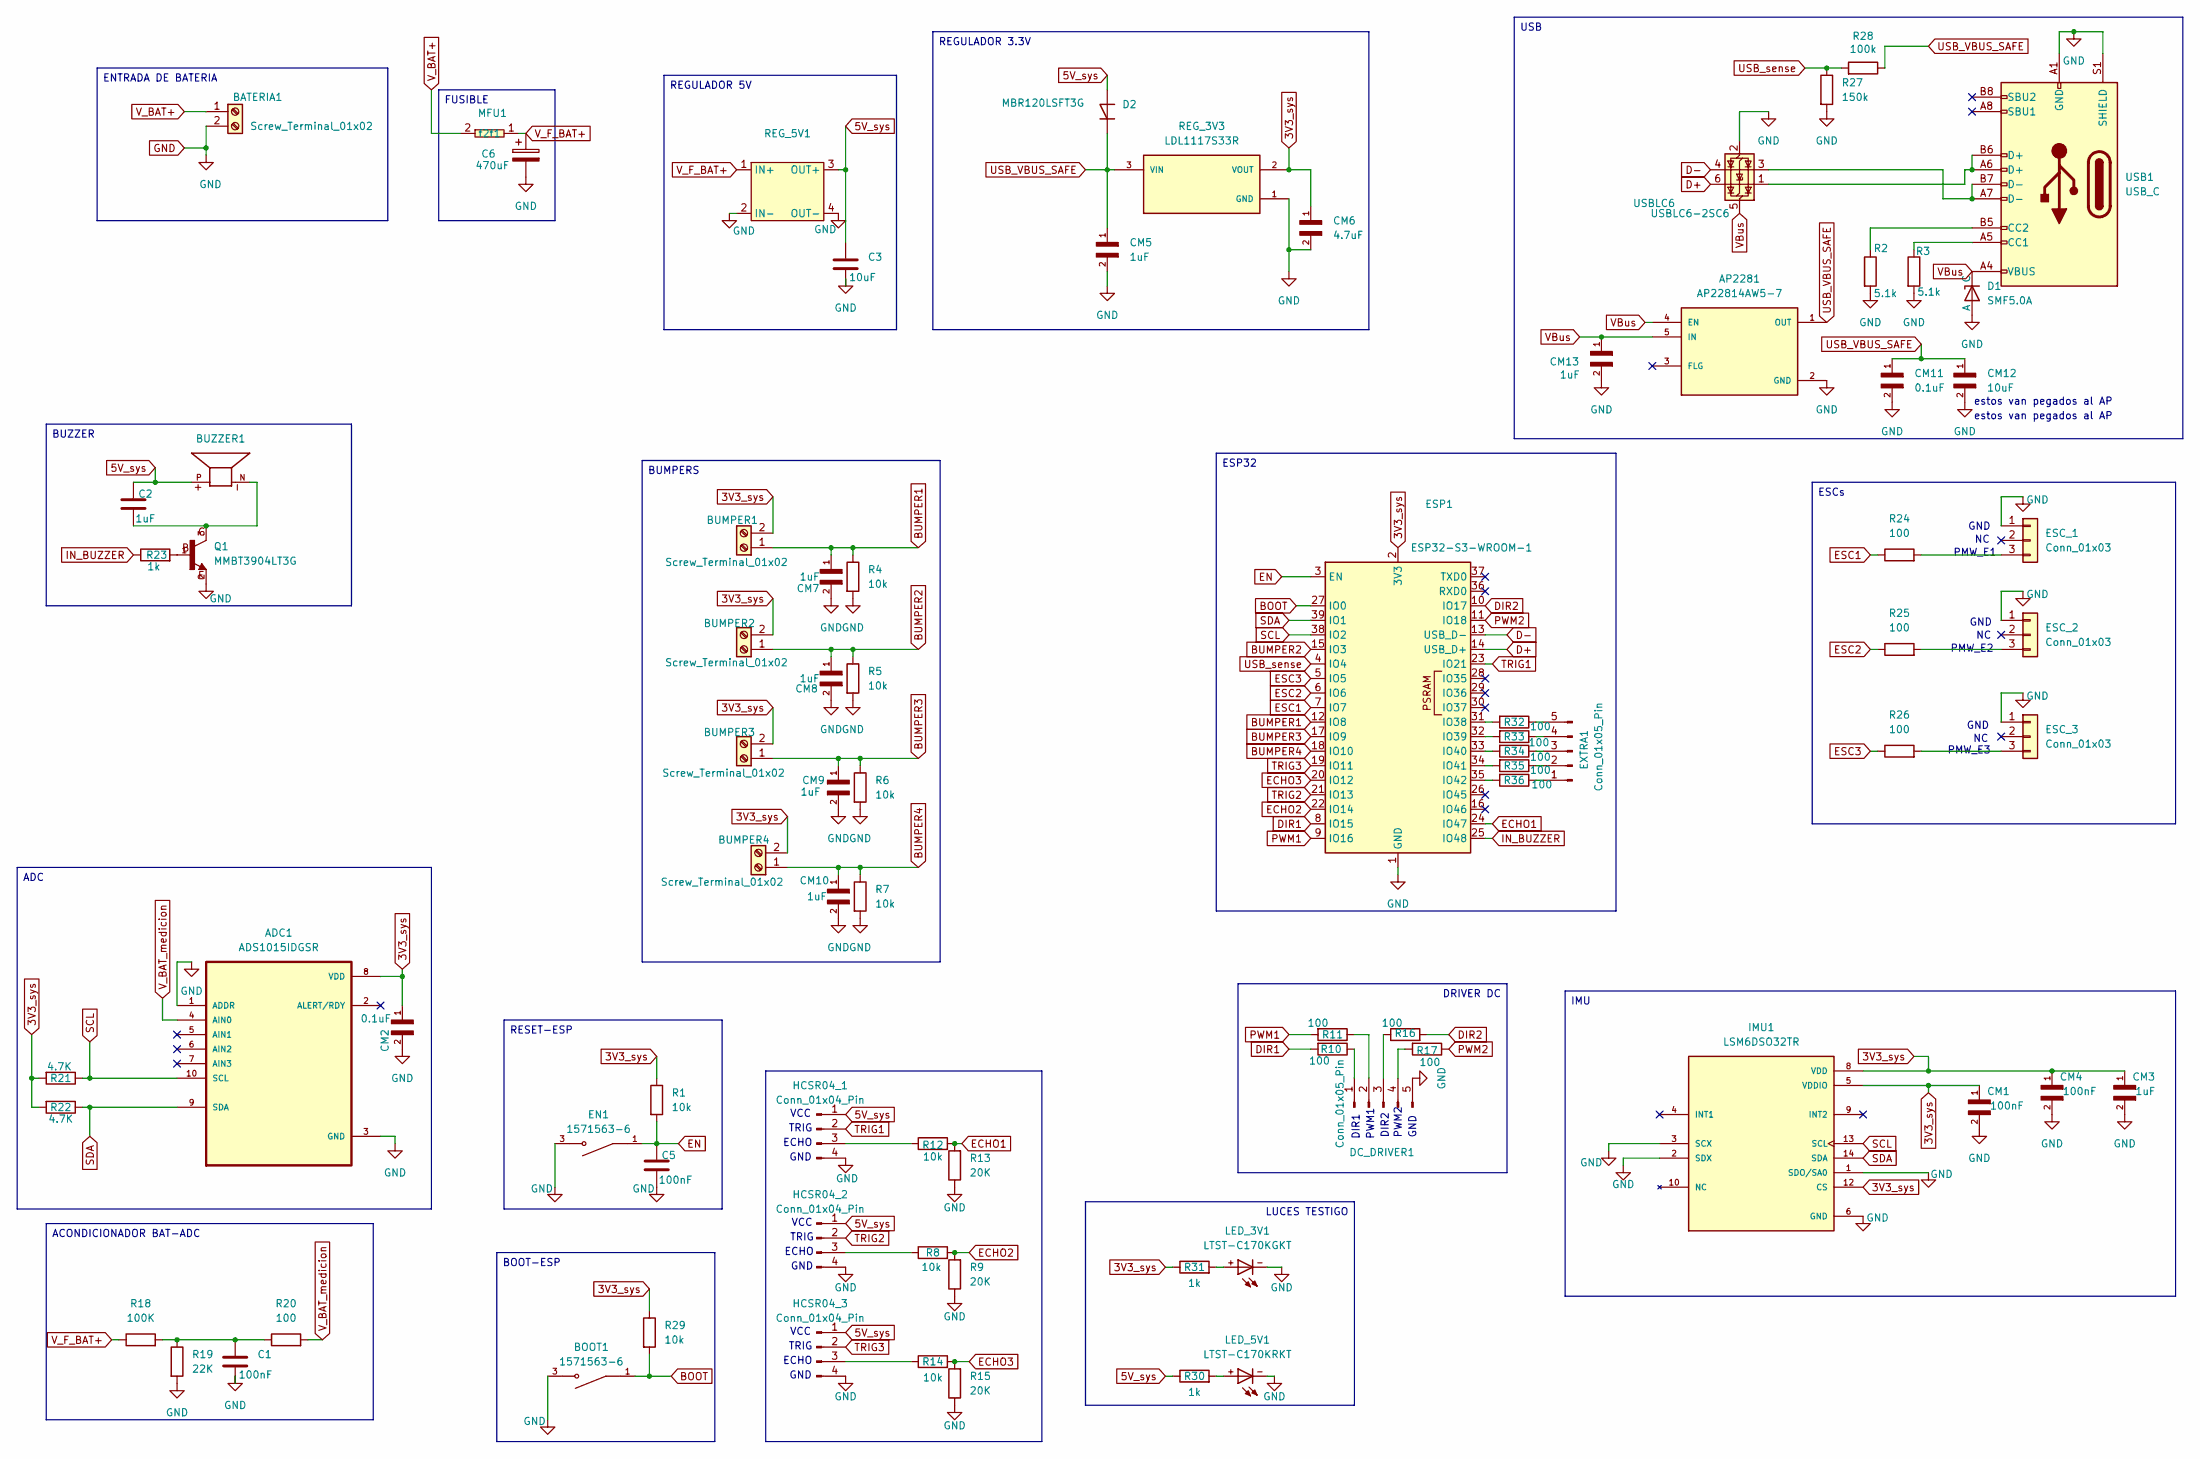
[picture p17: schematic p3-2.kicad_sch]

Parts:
ADC1: ADS1015IDGSR; SOP50P490X110-10N
AP2281: AP22814AW5-7; SOT95P285X140-5N; PARTREV 1
BATERIA1: Screw_Terminal_01x02; TerminalBlock_MetzConnect_Type055_RT01502HDWU_1x02_P5.00mm_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
BOOT1: 1571563-6; SW_1571563-6; PARTREV V
BUMPER1, BUMPER2, BUMPER3, BUMPER4: Screw_Terminal_01x02; TerminalBlock_Phoenix_MPT-0,5-2-2.54_1x02_P2.54mm_Horizontal
BUZZER1: CMI-9705-0580-SMT-TR; CUI_CMI-9705-0580-SMT-TR; PARTREV 1.0
C1, C5: 100nF; C_0805_2012Metric_Pad1.18x1.45mm_HandSolder
C2: 1uF; C_0805_2012Metric_Pad1.18x1.45mm_HandSolder
C3: 10uF; C_0805_2012Metric_Pad1.18x1.45mm_HandSolder
C6: 470uF; CP_Elec_10x10
CM1, CM4: 100nF; CAPC2012X140N; DigiKey_Part_Number 478-08056D104KAT2ACT-ND
CM2, CM11: 0.1uF; CAPC2012X140N; DigiKey_Part_Number 478-08056D104KAT2ACT-ND
CM3, CM5, CM7, CM8, CM9, CM10, CM13: 1uF; CAPC2012X140N; DigiKey_Part_Number 478-08056D104KAT2ACT-ND
CM6: 4.7uF; CAPC2012X140N; DigiKey_Part_Number 478-08056D104KAT2ACT-ND
CM12: 10uF; CAPC2012X140N; DigiKey_Part_Number 478-08056D104KAT2ACT-ND
D1: SMF5.0A; P37_SOD-123FL
D2: MBR120LSFT3G; D_SOD-123F
DC_DRIVER1: Conn_01x05_Pin; PinHeader_1x05_P2.54mm_Vertical
EN1: 1571563-6; SW_1571563-6; PARTREV V
ESC_1, ESC_2, ESC_3: Conn_01x03; PinHeader_1x03_P2.54mm_Vertical
ESP1: ESP32-S3-WROOM-1
EXTRA1: Conn_01x05_Pin; PinHeader_1x05_P2.54mm_Vertical
HCSR04_1, HCSR04_2, HCSR04_3: Conn_01x04_Pin; PinSocket_1x04_P2.54mm_Vertical
IMU1: LSM6DSO32TR; XDCR_LSM6DSO32TR; PARTREV 1
LED_3V1: LTST-C170KGKT; DIOC200X125X110
LED_5V1: LTST-C170KRKT; DIOC200X125X110
MFU1: MFU0805FF01000PW00
Q1: MMBT3904LT3G; SOT23; DigiKey_Part_Number MMBT3904LT3GOSCT-ND
R1, R4, R5, R6, R7, R8, R12, R14, R29: 10k; R_0805_2012Metric_Pad1.20x1.40mm_HandSolder
R2, R3: 5.1k; R_0805_2012Metric_Pad1.20x1.40mm_HandSolder
R9, R13, R15: 20K; R_0805_2012Metric_Pad1.20x1.40mm_HandSolder
R10, R11, R16, R17, R20, R24, R25, R26, R32, R33, R34, R35, R36: 100; R_0805_2012Metric_Pad1.20x1.40mm_HandSolder
R18: 100K; R_0805_2012Metric_Pad1.20x1.40mm_HandSolder
R19: 22K; R_0805_2012Metric_Pad1.20x1.40mm_HandSolder
R21, R22: 4.7K; R_0805_2012Metric_Pad1.20x1.40mm_HandSolder
R23, R30, R31: 1k; R_0805_2012Metric_Pad1.20x1.40mm_HandSolder
R27: 150k; R_0805_2012Metric_Pad1.20x1.40mm_HandSolder
R28: 100k; R_0805_2012Metric_Pad1.20x1.40mm_HandSolder
REG_3V3: LDL1117S33R; SOT230P700X180-4N; PARTREV 7
REG_5V1: MINI590
USB1: USB_C; USB_C_Receptacle_GCT_USB4105-xx-A_16P_TopMnt_Horizontal
USBLC6: USBLC6-2SC6; SOT-23-6

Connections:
3V3_sys: ADC1.8 (VDD), BUMPER1.2, BUMPER2.2, BUMPER3.2, BUMPER4.2, CM1.1, CM2.1, CM3.1, CM4.1, CM6.1, ESP1.2 (3V3), IMU1.5 (VDDIO), IMU1.8 (VDD), IMU1.12 (CS), R1.1, R21.2, R22.2, R29.1, R31.1, REG_3V3.2 (VOUT), REG_3V3.4 (VOUT)
5V_sys: BUZZER1.P, C2.1, C3.1, D2.2 (A), HCSR04_1.1, HCSR04_2.1, HCSR04_3.1, R30.1, REG_5V1.3 (OUT+)
BOOT: BOOT1.1, BOOT1.2, ESP1.27 (IO0), R29.2
BUMPER1: BUMPER1.1, CM7.1, ESP1.12 (IO8), R4.1
BUMPER2: BUMPER2.1, CM8.1, ESP1.15 (IO3), R5.1
BUMPER3: BUMPER3.1, CM9.1, ESP1.17 (IO9), R6.1
BUMPER4: BUMPER4.1, CM10.1, ESP1.18 (IO10), R7.1
D+: ESP1.14 (USB_D+), USBLC6.6 (I/O1)
D-: ESP1.13 (USB_D-), USBLC6.4 (I/O2)
DIR1: ESP1.8 (IO15), R10.2
DIR2: ESP1.10 (IO17), R16.2
ECHO1: ESP1.24 (IO47), R12.2, R13.2
ECHO2: ESP1.22 (IO14), R8.2, R9.2
ECHO3: ESP1.20 (IO12), R14.2, R15.2
EN: C5.1, EN1.1, EN1.2, ESP1.3 (EN), R1.2
ESC1: ESP1.7 (IO7), R24.1
ESC2: ESP1.6 (IO6), R25.1
ESC3: ESP1.5 (IO5), R26.1
GND: ADC1.1 (ADDR), ADC1.3 (GND), AP2281.2 (GND), BATERIA1.2, BOOT1.3, BOOT1.4, C1.2, C3.2, C5.2, C6.2, CM1.2, CM2.2, CM3.2, CM4.2, CM5.2, CM6.2, CM7.2, CM8.2, CM9.2, CM10.2, CM11.2, CM12.2, CM13.2, D1.2 (A), DC_DRIVER1.5, EN1.3, EN1.4, ESC_1.1, ESC_2.1, ESC_3.1, ESP1.1 (GND), ESP1.40 (GND), ESP1.41 (GND), HCSR04_1.4, HCSR04_2.4, HCSR04_3.4, IMU1.1 (SDO/SA0), IMU1.2 (SDX), IMU1.3 (SCX), IMU1.6 (GND), IMU1.7 (GND), LED_3V1.-, LED_5V1.-, Q1.2, R2.2, R3.2, R4.2, R5.2, R6.2, R7.2, R9.1, R13.1, R15.1, R19.2, R27.2, REG_3V3.1 (GND), REG_5V1.2 (IN-), REG_5V1.4 (OUT-), USB1.A1 (GND), USB1.A12 (GND), USB1.B1 (GND), USB1.B12 (GND), USB1.S1 (SHIELD), USBLC6.2 (GND); also elsewhere on the board
IN_BUZZER: ESP1.25 (IO48), R23.1
unnamed: BUZZER1.N, C2.2, Q1.3
unnamed: C1.1, R18.2, R19.1, R20.1
unnamed: DC_DRIVER1.1, R10.1
unnamed: DC_DRIVER1.2, R11.1
unnamed: DC_DRIVER1.3, R16.1
unnamed: DC_DRIVER1.4, R17.2
unnamed: ESC_1.3, R24.2
unnamed: ESC_2.3, R25.2
unnamed: ESC_3.3, R26.2
unnamed: ESP1.31 (IO38), R32.2
unnamed: ESP1.32 (IO39), R33.2
unnamed: ESP1.33 (IO40), R34.2
unnamed: ESP1.34 (IO41), R35.2
unnamed: ESP1.35 (IO42), R36.2
unnamed: EXTRA1.1, R36.1
unnamed: EXTRA1.2, R35.1
unnamed: EXTRA1.3, R34.1
unnamed: EXTRA1.4, R33.1
unnamed: EXTRA1.5, R32.1
unnamed: HCSR04_1.3, R12.1
unnamed: HCSR04_2.3, R8.1
unnamed: HCSR04_3.3, R14.1
unnamed: LED_3V1.+, R31.2
unnamed: LED_5V1.+, R30.2
unnamed: Q1.1, R23.2
unnamed: R3.1, USB1.A5 (CC1)
unnamed: R2.1, USB1.B5 (CC2)
unnamed: USB1.A6 (D+), USB1.B6 (D+), USBLC6.1 (I/O1)
unnamed: USB1.A7 (D-), USB1.B7 (D-), USBLC6.3 (I/O2)
PWM1: ESP1.9 (IO16), R11.2
PWM2: ESP1.11 (IO18), R17.1
SCL: ADC1.10 (SCL), ESP1.38 (IO2), IMU1.13 (SCL), R21.1
SDA: ADC1.9 (SDA), ESP1.39 (IO1), IMU1.14 (SDA), R22.1
TRIG1: ESP1.23 (IO21), HCSR04_1.2
TRIG2: ESP1.21 (IO13), HCSR04_2.2
TRIG3: ESP1.19 (IO11), HCSR04_3.2
USB_VBUS_SAFE: AP2281.1 (OUT), CM5.1, CM11.1, CM12.1, D2.1 (K), R28.1, REG_3V3.3 (VIN)
USB_sense: ESP1.4 (IO4), R27.1, R28.2
VBus: AP2281.4 (EN), AP2281.5 (IN), CM13.1, D1.1 (C), USB1.A4 (VBUS), USB1.A9 (VBUS), USB1.B4 (VBUS), USB1.B9 (VBUS), USBLC6.5 (VBUS)
V_BAT+: BATERIA1.1, MFU1.2 (f2)
V_BAT_medicion: ADC1.4 (AIN0), R20.2
V_F_BAT+: C6.1, MFU1.1 (f1), R18.1, REG_5V1.1 (IN+)

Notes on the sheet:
TRIG
PWM2
GND
estos van pegados al AP
VCC
GND
ECHO
PMW_E2
PMW_E3
DIR2
DIR1
PWM1
PMW_E1
ADC
REGULADOR 3.3V
RESET-ESP
ENTRADA DE BATERIA
DRIVER DC
BUMPERS
BUZZER
BOOT-ESP
ESP32
LUCES TESTIGO
ESCs
ACONDICIONADOR BAT-ADC
USB
REGULADOR 5V
IMU
FUSIBLE

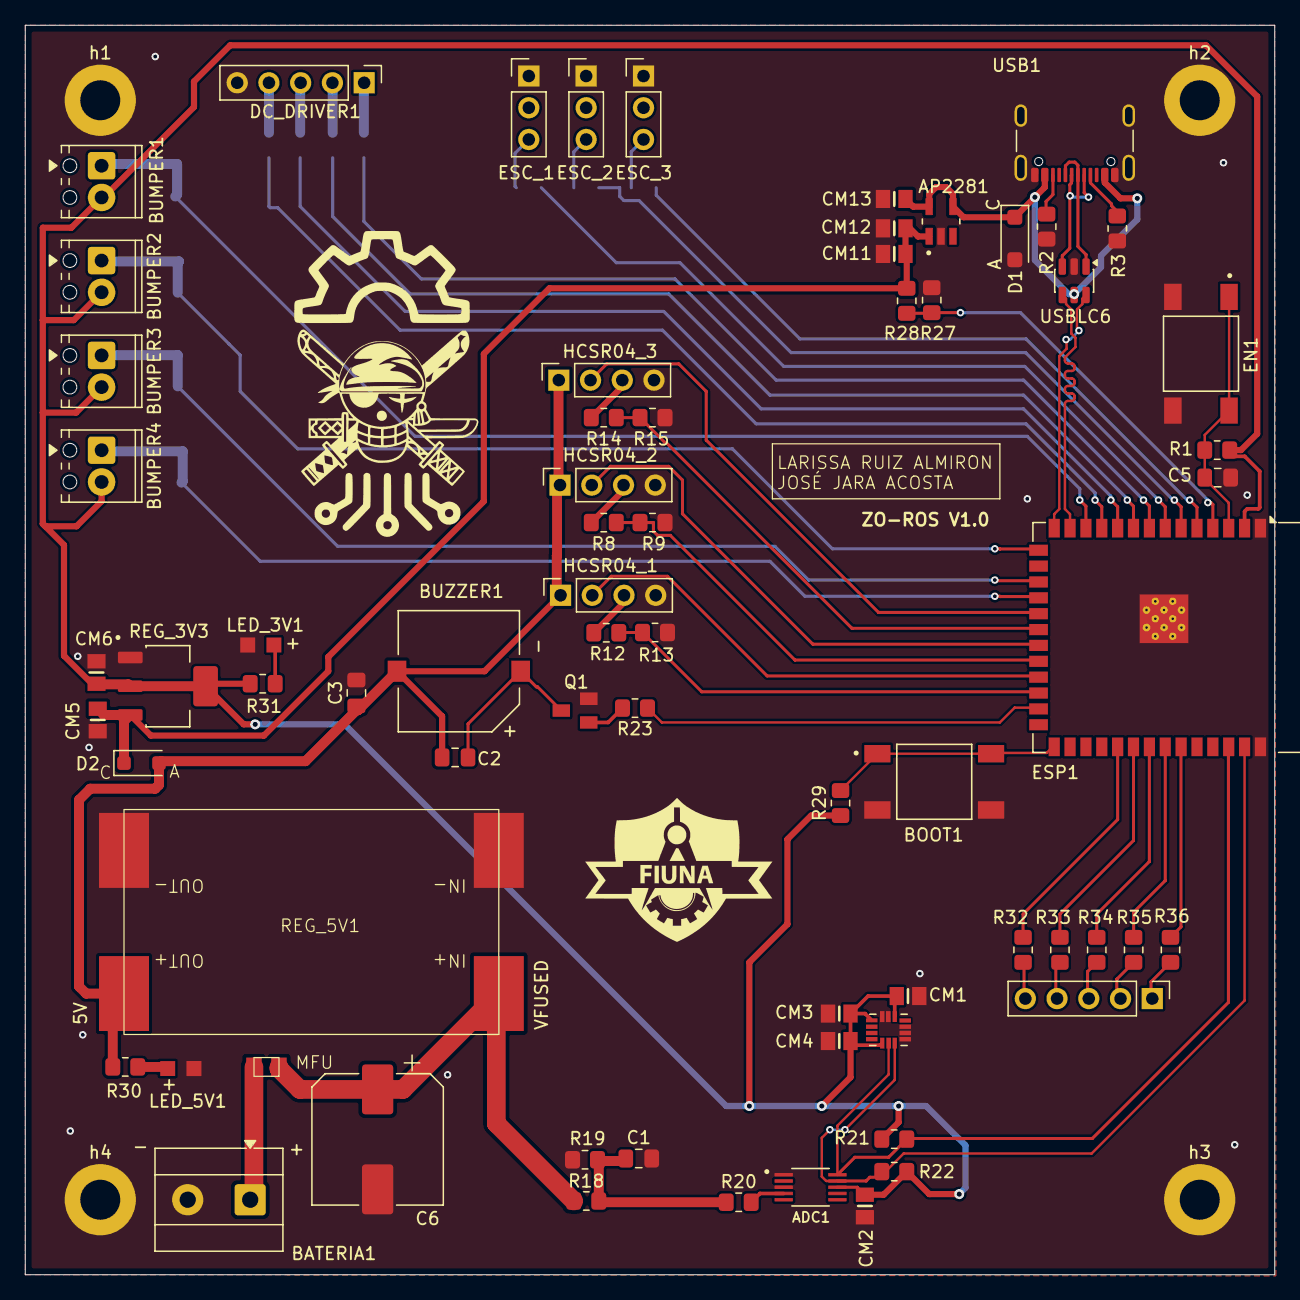
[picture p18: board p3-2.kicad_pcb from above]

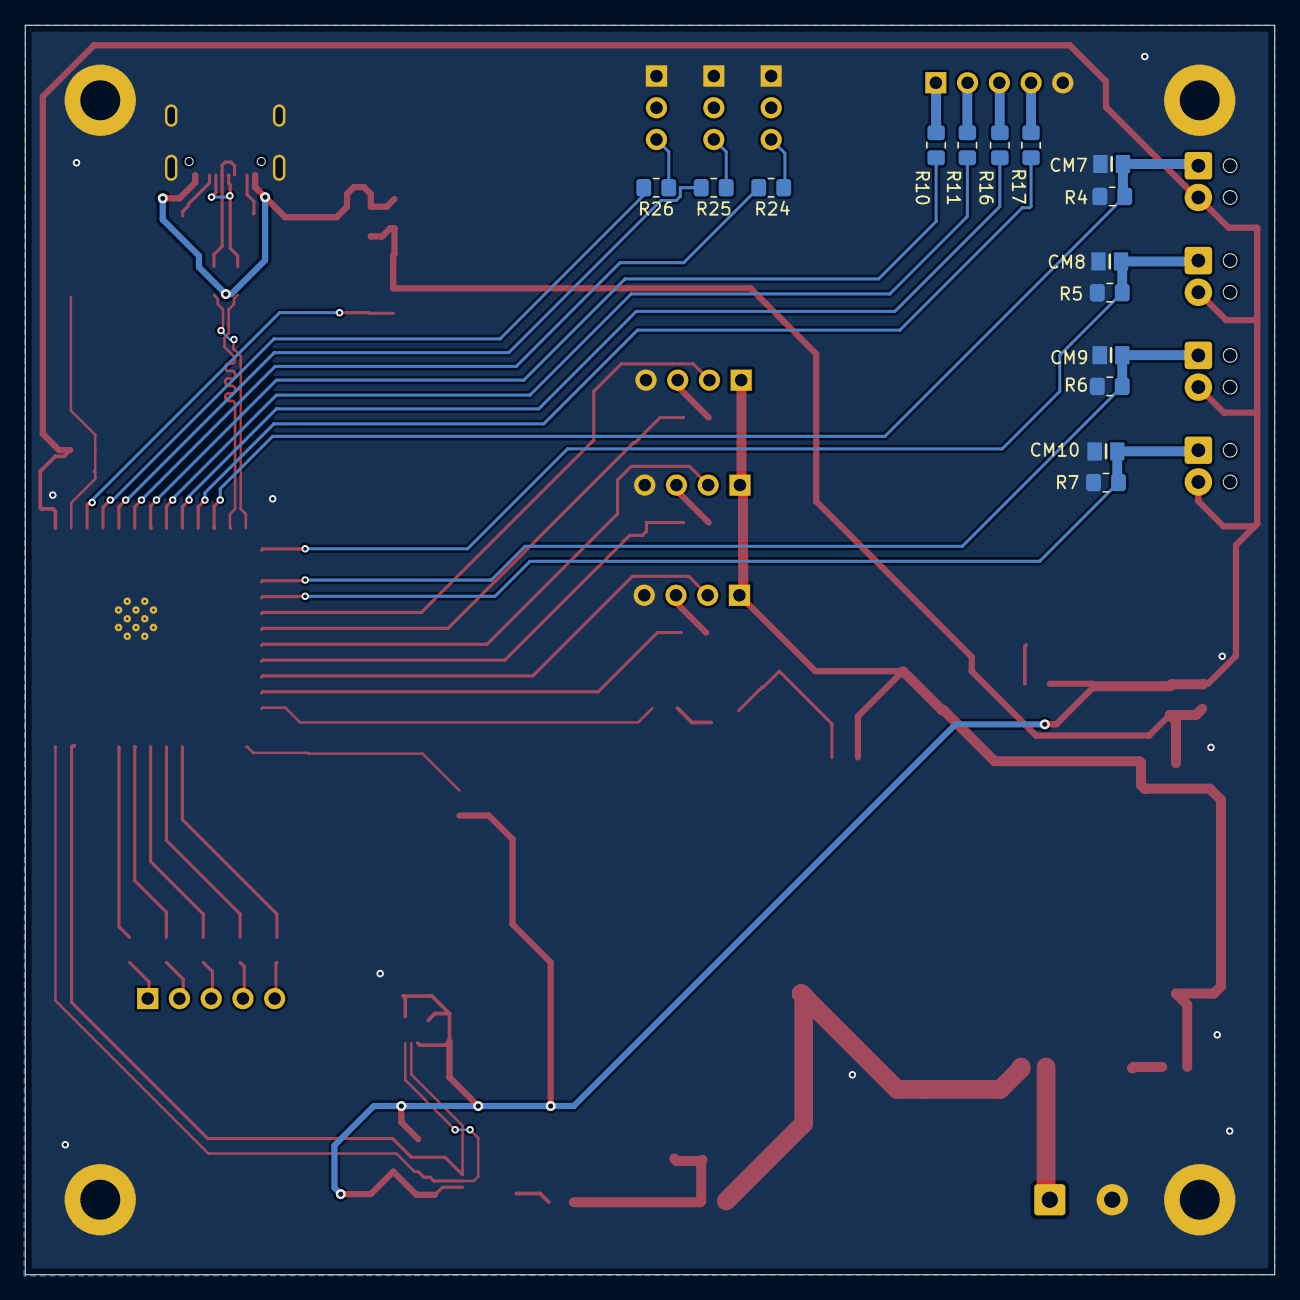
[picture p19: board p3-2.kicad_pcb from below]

Board: 2 copper layers, 100.0 x 100.0 mm, 90 parts (15 on the bottom side), 62 nets.

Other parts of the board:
FIUNA: LOGO; logo
ZORO: LOGO; zoro
h1, h2, h3, h4: MountingHole_3.2mm_M3_ISO7380_Pad

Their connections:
GND: h1.1, h2.2, h3.3, h4.4; also elsewhere on the board
